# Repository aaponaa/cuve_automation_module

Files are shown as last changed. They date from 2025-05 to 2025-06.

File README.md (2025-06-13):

# 💧 Water Tank Monitor with ESP32 : RootCtrl

An all-in-one ESP32-based water tank monitoring system that measures:

- Water level using an ultrasonic sensor (AJ-SR04M / HC-SR04)
- Water temperature using DS18B20
- Outside temperature and humidity using a DHT22
- Pump/relay control via web interface or MQTT
- MQTT integration with configurable topic publishing
- Web UI with AJAX updates and settings
- WiFiManager for first-time WiFi configuration

---

## 📦 Features

- 🌀 Real-time water level calculation in cm and %
- 🌡️ Dual temperature sensing: water & ambient
- 📊 Volume estimation based on tank shape (rectangular or cylindrical)
- ⚙️ Web interface for configuration, calibration, and manual control
- 🛰️ MQTT support with configurable topics (sensor data + relay state)
- 📱 Works with Home Assistant or any MQTT broker
- 🔧 EEPROM storage of all settings (WiFi, MQTT, tank, interval, etc.)
- 🔌 Relay control from web or MQTT (`/relay_cmd`)

---

## 🧰 Hardware Required

| Component | Example GPIO | Notes |
|---|---|---|
| ESP32 WROOM-32 | - | Main microcontroller |
| Ultrasonic Sensor (AJ-SR04M / HC-SR04) | TRIG: GPIO17 / ECHO: GPIO18 | With voltage divider on ECHO |
| DS18B20 Temperature Sensor| GPIO21 | Requires 4.7kΩ pull-up to 3.3V |
| DHT22 Temp/Humidity Sensor| GPIO19 | Requires 4.7kΩ pull-up to 3.3V |
| Relay Module (SRD-05VDC-SL-C) | GPIO23 | 5V-controlled |
| Resistors | - | 2×1kΩ + 1×4.7kΩ (voltage divider) |

> ✅ Use a voltage divider (2×1kΩ + 4.7kΩ) on the ultrasonic sensor's ECHO pin to protect ESP32 GPIO from 5V logic levels.

---

## 🔌 Wiring Diagram

See Wiring Diagram :

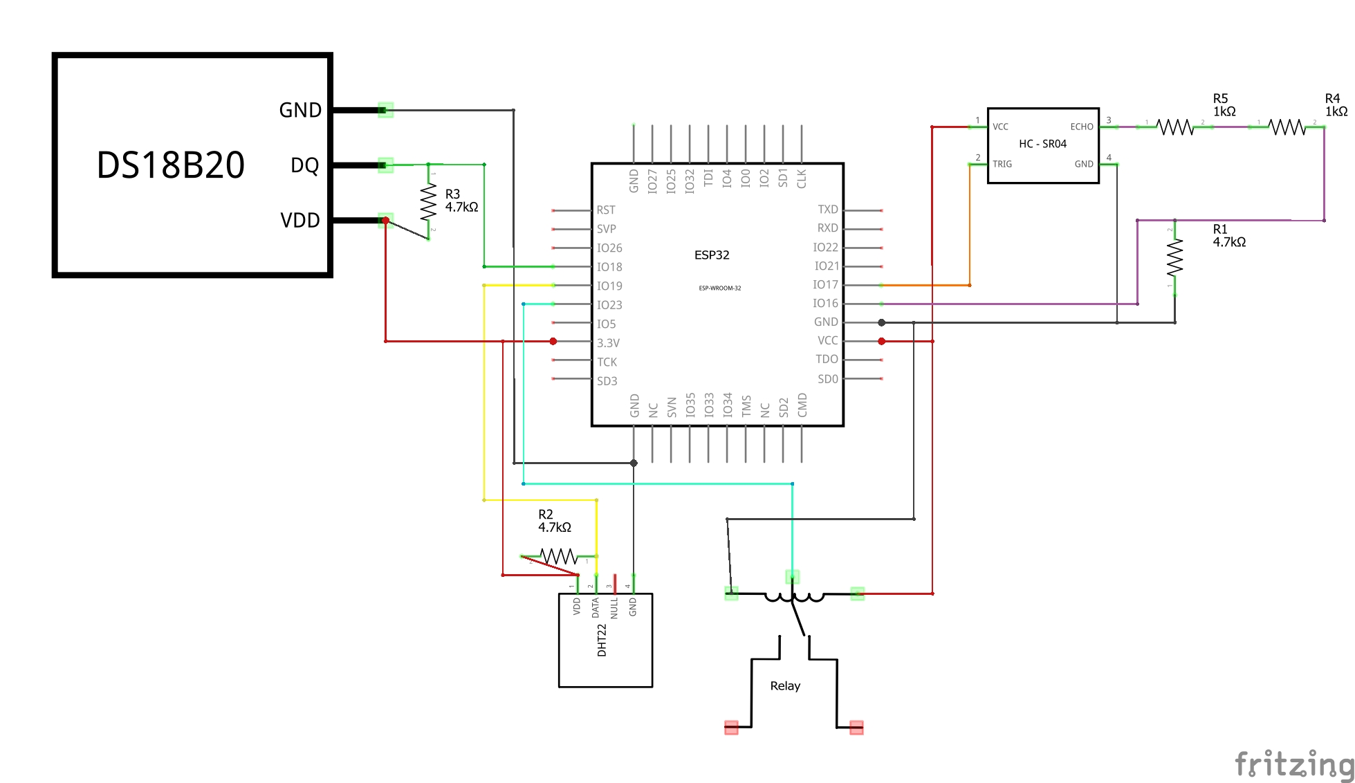
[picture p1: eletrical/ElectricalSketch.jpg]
Wiring Diagram
 

or Fritzing file for full details.

You can also reference this simplified table:

| Module | VCC  | GND | ESP32 GPIO | Resistors Needed |
| --- | ---- | --- | --- | --- |
| AJ-SR04M | 5V | GND | TRIG → GPIO17 | None |
| AJ-SR04M | | | ECHO → GPIO18 | 2×1kΩ + 1×4.7kΩ (divider) |
| DS18B20 | 3.3V | GND | DATA → GPIO21 | 1×4.7kΩ (pull-up to 3.3V) |
| DHT22 | 3.3V | GND | DATA → GPIO19 | 1×4.7kΩ (pull-up to 3.3V) |
| Relay Module | 5V | GND | IN → GPIO23 | None |

---

## 🌐 Web Interface

Accessible via browser at the ESP32 IP address.  
Features:

- Live dashboard with temperature, level, volume, % fill
- Manual relay control
- Tank configuration (shape, size)
- MQTT settings
- Update read/publish intervals
- Factory reset button

---

## ☁️ MQTT Topics

All topics are prefixed with your configured tank name (e.g. `cuve_1`).

| Topic | Description |
|---|---|
| `<prefix>/water_distance` | Distance from sensor to surface |
| `<prefix>/water_height` | Height of water in cm |
| `<prefix>/water_percent`  | Percentage fill |
| `<prefix>/water_volume` | Estimated volume in liters |
| `<prefix>/water_temp` | Water temperature (DS18B20) |
| `<prefix>/outside_temp` | Air temperature (DHT22) |
| `<prefix>/outside_humi` | Humidity (DHT22) |
| `<prefix>/relay_state` | ON/OFF state of the relay |

> To control the relay remotely:  
> Publish `"on"` or `"off"` to `<prefix>/relay_cmd`

---

## ⚙️ Settings

Stored in EEPROM via the `Preferences` API:

- Tank name
- Tank shape and dimensions
- Max water height (calibration)
- MQTT credentials and interval
- Read interval for sensors
- Enabled MQTT topics

---

## 🔧 Getting Started

1. Flash the firmware via Arduino IDE or PlatformIO
2. Connect to the WiFi AP `Tank_Automation_Config`
3. Go to `http://192.168.4.1` and enter your WiFi credentials
4. The ESP32 will reboot and be accessible on your LAN
5. Access the dashboard and configure your tank and MQTT

---

## 🚀 To Do / Ideas

- Support multiple tanks via web tabs
- OTA firmware updates
- Home Assistant full integration

---

## 🧑‍💻 Author

Benjamin Maas — [@GitHub](https://github.com/yourusername)  
Feel free to fork, use, and improve!

---

## Licence

Ce projet est sous licence **CC BY-NC 4.0** — utilisation commerciale interdite.  
Détails : [LICENSE](./LICENSE)



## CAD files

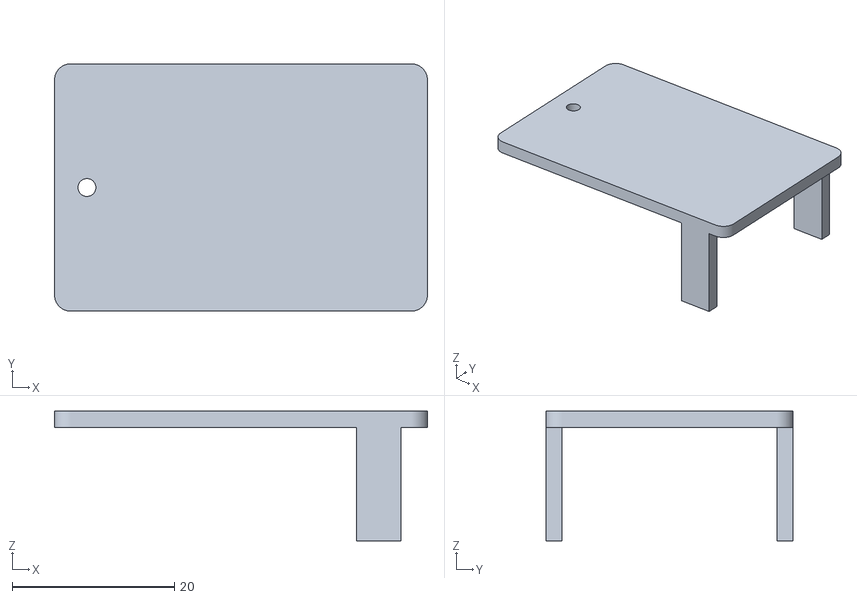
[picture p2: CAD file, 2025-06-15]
stl/relay_case-Cap.stl
46.0 x 30.5 x 16.0

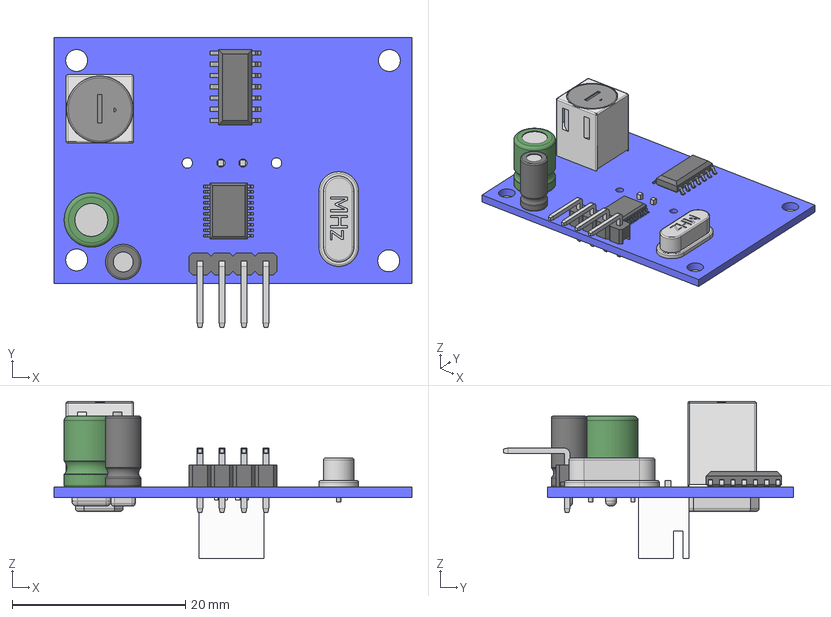
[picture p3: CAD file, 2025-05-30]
stl/StepModels/JSN20.stp
41.4 x 33.5 x 18.1 mm

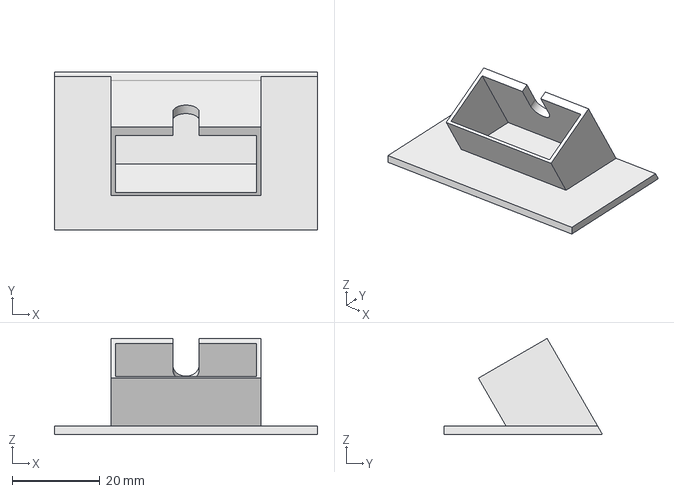
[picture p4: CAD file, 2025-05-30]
stl/Thingiverse/DHT22/DHT_Lid.FCStd
60.0 x 36.0 x 21.9 mm

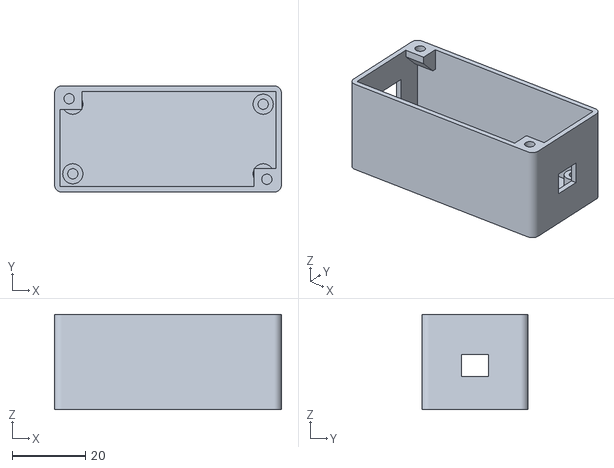
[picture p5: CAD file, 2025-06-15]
stl/alimentation_case-Box.stl
62.0 x 29.0 x 26.0

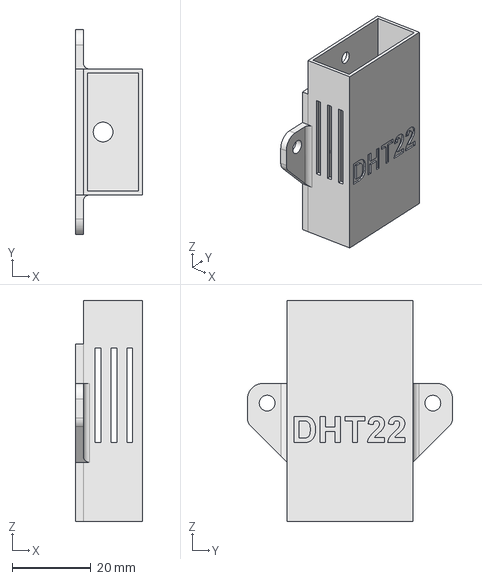
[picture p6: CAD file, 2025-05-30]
stl/Thingiverse/DHT22/DHT_Box.FCStd
17.0 x 52.0 x 56.0 mm

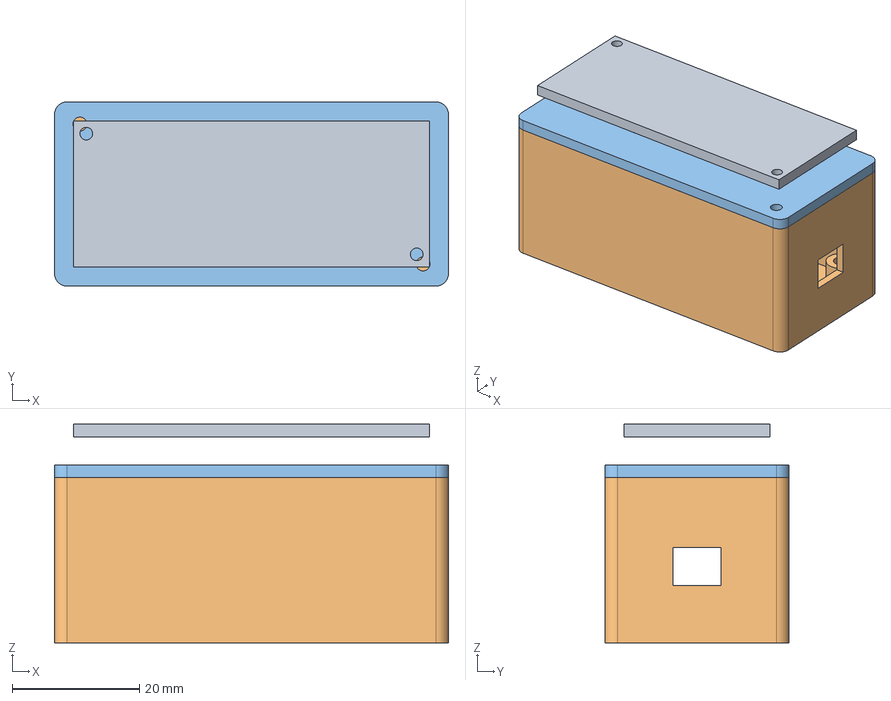
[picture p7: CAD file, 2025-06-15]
stl/alimentation_case.FCStd
62.0 x 29.0 x 34.4 mm
CardSize
Cap

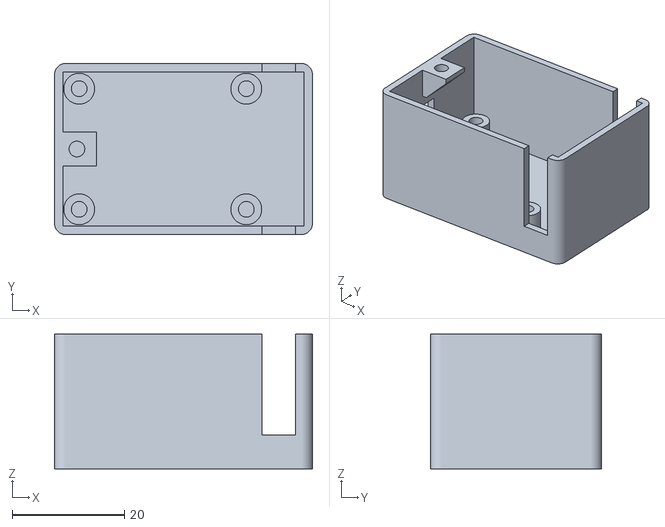
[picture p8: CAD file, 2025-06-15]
stl/relay_case-Box.stl
46.0 x 30.5 x 24.0

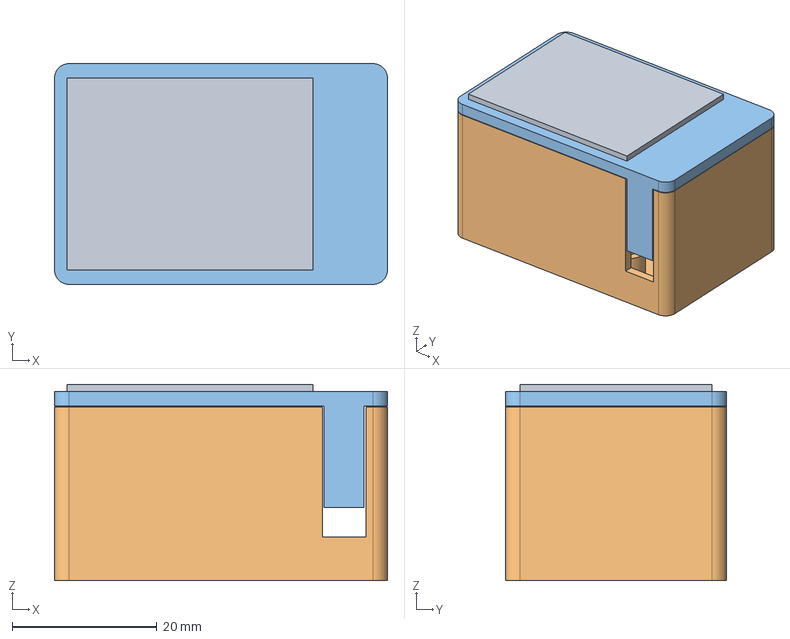
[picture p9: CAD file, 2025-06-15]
stl/relay_case.FCStd
46.0 x 30.5 x 27.1 mm
CardPatern
Cap

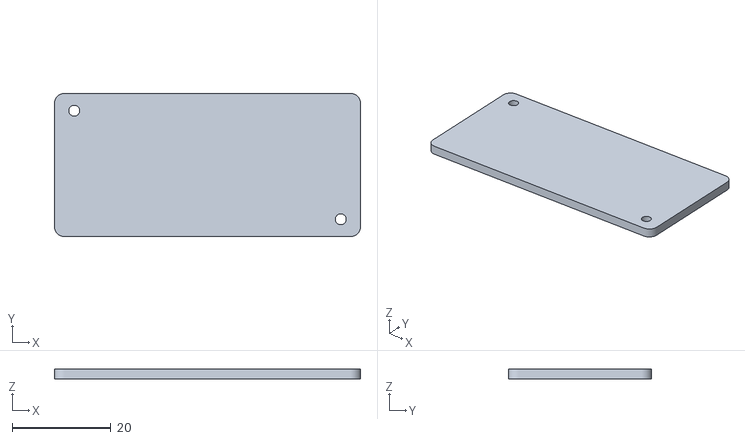
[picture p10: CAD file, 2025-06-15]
stl/alimentation_case-Cap.stl
62.0 x 29.0 x 2.00

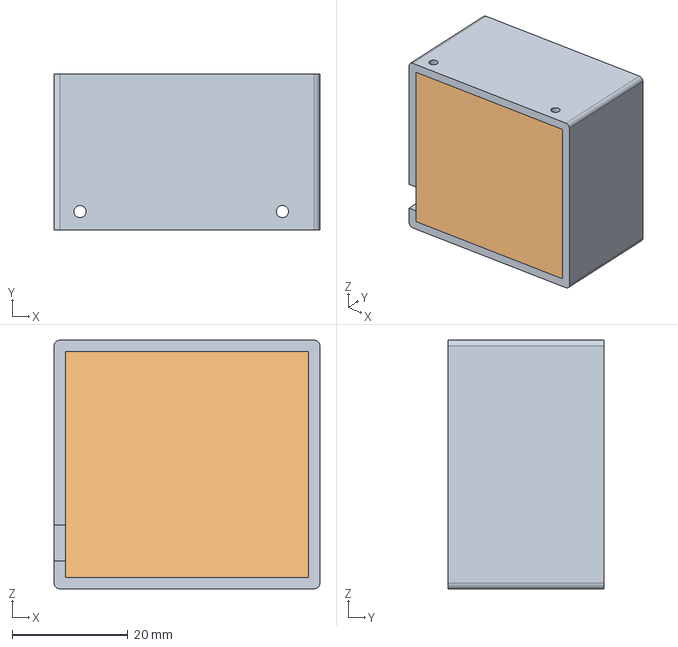
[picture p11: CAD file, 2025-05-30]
stl/sketch_case.FCStd
46.0 x 27.0 x 43.0 mm
Case
Top

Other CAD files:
stl/Thingiverse/DHT22/DHT_Box.stl
stl/Thingiverse/DHT22/DHT_Lid.stl

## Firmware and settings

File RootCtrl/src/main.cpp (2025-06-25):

#include <Arduino.h>
#include "config.h"
#include "sensors/sensors.h"
#include "sensors/relay.h"
#include "services/mqtt.h"
#include "services/web_routes.h"
#include "services/settings.h"
#include "services/wifi_handler.h"
#include "services/logger.h"

void setup() {
  Serial.begin(115200);
  
  // Initialize logger first
  Logger::getInstance().setSerialEnabled(true);
  Logger::getInstance().setMinLevel(LOG_DEBUG);
  
  LOG_INFO("SYSTEM", "Starting Water Tank Monitor " + String(FW_VERSION));
  LOG_INFO("SYSTEM", "ESP32 Chip ID: " + String((uint32_t)ESP.getEfuseMac(), HEX));
  LOG_INFO("SYSTEM", "Free heap: " + String(ESP.getFreeHeap()) + " bytes");
  
  initWifi();
  initSettings();
  initRelay();
  initSensors();
  initWebServer();
  initMqtt();
  
  LOG_INFO("SYSTEM", "Setup complete. System ready.");
}

void loop() {
  server.handleClient();
  readSensorsLoop();
  handleMqttLoop();
  
  // Log system health every 30 seconds
  static unsigned long lastHealthLog = 0;
  if (millis() - lastHealthLog > 300000) {
    LOG_DEBUG("SYSTEM", "Free heap: " + String(ESP.getFreeHeap()) + " bytes");
    LOG_DEBUG("SYSTEM", "Uptime: " + String(millis() / 1000) + " seconds");
    lastHealthLog = millis();
  }
}

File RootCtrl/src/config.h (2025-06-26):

#ifndef CONFIG_H
#define CONFIG_H

#include <Arduino.h>
#include <Preferences.h>
#include <PubSubClient.h>
#include <WebServer.h>
#include <OneWire.h>
#include <DallasTemperature.h>
#include <DHT.h>
#include <WiFiClient.h>

// ========== GENERAL SETTINGS ==========

#define FW_VERSION "v1.0.2"
extern String fw_version;

//#define USE_A02YYUW false  // Set to false to use SR04M

// ========== PIN DEFINITIONS ==========

// Ultrasonic sensors
#define TRIG_PIN 17
#define ECHO_PIN 16  // Only used for SR04M

// A02YYUW
#define SENSOR_RX_PIN 26  // A02YYUW TX → ESP32 RX (SoftwareSerial not needed with HardwareSerial2)

// DS18B20
#define ONE_WIRE_BUS 18

// DHT22
#define DHTPIN 33
#define DHTTYPE DHT22

// Relay
#define RELAY_PIN 27
#define RELAY_ACTIVE_LOW false

// ========== GLOBALS ==========

// Sensors 
extern bool use_dht;
extern bool use_ds18b20;
extern int ultrasonic_mode;  // 0 = aucune, 1 = SR04M, 2 = A02YYUW

// Web server and MQTT
extern WebServer server;
extern WiFiClient espClient;
extern PubSubClient mqtt;
extern Preferences prefs;

// Tank config
extern String tank_name;
extern int tank_shape;
extern float tank_height_cm;
extern float tank_length_cm;
extern float tank_width_cm;
extern float tank_diameter_cm;
extern float eau_max_cm;
extern float cuve_volume_l;

// Sensor values
extern float current_temp;
extern float outside_temp;
extern float outside_humi;
extern bool pump_is_on;

// Refresh intervals
extern unsigned long temp_refresh_ms;
extern unsigned long mqtt_publish_ms;

// MQTT config
extern String mqtt_host;
extern String mqtt_username;
extern String mqtt_password;
extern bool mqtt_enabled;

#endif // CONFIG_H

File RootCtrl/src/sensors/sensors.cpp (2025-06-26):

#include "sensors.h"
#include "../services/logger.h"

// DS18B20
OneWire oneWire(ONE_WIRE_BUS);
DallasTemperature ds18b20(&oneWire);

// DHT22
DHT dht(DHTPIN, DHTTYPE);

// A02YYUW via Serial2
HardwareSerial mySerial(2);  // UART2 (GPIO26 RX)

unsigned long lastDhtRead = 0;
unsigned long lastDs18Read = 0;
float last_distance = 0;

int dhtFailCount = 0;
const int maxDhtFail = 4;

void initSensors() {
  LOG_INFO("SENSORS", "Initializing sensors...");

  dht.begin();
  LOG_INFO("SENSORS", "DHT22 initialized on pin " + String(DHTPIN));
  
  ds18b20.begin();
  LOG_INFO("SENSORS", "DS18B20 initialized on pin " + String(ONE_WIRE_BUS));

  if (ultrasonic_mode == 2) {
    mySerial.begin(9600, SERIAL_8N1, SENSOR_RX_PIN, -1);  // A02YYUW
    LOG_INFO("SENSORS", "A02YYUW initialized on RX pin " + String(SENSOR_RX_PIN));
  } else if (ultrasonic_mode == 1) {
    pinMode(TRIG_PIN, OUTPUT);
    pinMode(ECHO_PIN, INPUT);
    LOG_INFO("SENSORS", "SR04M initialized - TRIG: " + String(TRIG_PIN) + ", ECHO: " + String(ECHO_PIN));
  }
}

void readSensorsLoop() {
  unsigned long now = millis();

  if (use_dht && now - lastDhtRead > temp_refresh_ms) {
    readDHT();
    lastDhtRead = now;
  }

  if (use_ds18b20 && now - lastDs18Read > temp_refresh_ms) {
    readDS18B20();
    lastDs18Read = now;
  }

  if (ultrasonic_mode == 2) {
    float newDistance = readA02YYUW();
    if (newDistance > 0) {
      last_distance = newDistance;
    }
  }
}

void readDHT() {
  float t = dht.readTemperature();
  float h = dht.readHumidity();

  if (isnan(t) || isnan(h)) {
    dhtFailCount++;
    LOG_WARNING("DHT22", "Read failed (count: " + String(dhtFailCount) + "/" + String(maxDhtFail) + ")");
  } else {
    outside_temp = t;
    outside_humi = h;
    dhtFailCount = 0;
    //LOG_DEBUG("DHT22", "Temp: " + String(t, 1) + "°C, Humidity: " + String(h, 1) + "%");
  }

  if (dhtFailCount >= maxDhtFail) {
    LOG_ERROR("DHT22", "Max failures reached, reinitializing...");
    dht.begin();
    dhtFailCount = 0;
  }
}

void readDS18B20() {
  ds18b20.requestTemperatures();
  float temp = ds18b20.getTempCByIndex(0);
  
  if (temp == DEVICE_DISCONNECTED_C) {
    LOG_ERROR("DS18B20", "Sensor disconnected or read error");
  } else {
    current_temp = temp;
    //LOG_DEBUG("DS18B20", "Water temp: " + String(temp, 1) + "°C");
  }
}

float readSR04M() {
  //LOG_DEBUG("SR04M", "Starting measurement...");
  float sum = 0;
  int validReadings = 0;
  const int samples = 5;
  
  for (int i = 0; i < samples; i++) {
    digitalWrite(TRIG_PIN, LOW);
    delayMicroseconds(2);
    digitalWrite(TRIG_PIN, HIGH);
    delayMicroseconds(10);
    digitalWrite(TRIG_PIN, LOW);
    
    long duration = pulseIn(ECHO_PIN, HIGH, 30000);
    
    if (duration > 0) {
      float distance = duration * 0.0343 / 2.0;
      sum += distance;
      validReadings++;
      //LOG_DEBUG("SR04M", "Sample " + String(i) + ": " + String(distance, 1) + " cm");
    } else {
      LOG_WARNING("SR04M", "Sample " + String(i) + " timeout");
    }
    
    delay(10);
  }
  
  if (validReadings > 0) {
    float avg = sum / validReadings;
    //LOG_INFO("SR04M", "Average distance: " + String(avg, 1) + " cm (" + String(validReadings) + " valid samples)");
    return avg;
  } else {
    LOG_ERROR("SR04M", "No valid readings");
    return -1.0;
  }
}

float readA02YYUW() {
  static unsigned long lastGoodReading = 0;
  static int consecutiveErrors = 0;

  const unsigned long timeout = 100;  // Timeout for waiting full packet (ms)
  unsigned long startMillis = millis();

  while (millis() - startMillis < timeout) {
    // Ensure we have at least 4 bytes
    if (mySerial.available() >= 4) {
      if (mySerial.peek() == 0xFF) {
        byte buffer[4];
        mySerial.readBytes(buffer, 4);

        int distance = (buffer[1] << 8) | buffer[2];
        byte checksum = (buffer[0] + buffer[1] + buffer[2]) & 0xFF;

        if (checksum == buffer[3]) {
          if (distance >= 30 && distance <= 7500) {
            float distanceCm = distance / 10.0;
            lastGoodReading = millis();
            consecutiveErrors = 0;
            LOG_INFO("A02YYUW", "Valid reading: " + String(distanceCm, 1) + " cm");
            return distanceCm;
          } else {
            LOG_WARNING("A02YYUW", "Distance out of range: " + String(distance));
          }
        } else {
          LOG_WARNING("A02YYUW", "Checksum error");
        }
      } else {
        // Discard bytes until we find 0xFF
        mySerial.read();
      }
    }
  }

  if (millis() - lastGoodReading > 5000) {
    consecutiveErrors++;
    if (consecutiveErrors % 10 == 0) {
      LOG_ERROR("A02YYUW", "No valid readings for " + String((millis() - lastGoodReading) / 1000) + " seconds");
    }
  }

  return -1.0;
}



float calculateVolumeLiters(float height_cm) {
  if (tank_shape == 1) {  // Cylinder
    return (PI * pow(tank_diameter_cm / 2, 2) * height_cm) / 1000.0;
  } else {
    return (tank_length_cm * tank_width_cm * height_cm) / 1000.0;
  }
}

float measureDistance() {
  if (ultrasonic_mode == 2) {
    return last_distance;
  } else if (ultrasonic_mode == 1) {
    return readSR04M();
  } else {
    return -1.0;
  }
}

void handleCalibrate() {
  LOG_INFO("CALIB", "Starting calibration...");
  float distance = measureDistance();
  
  if (distance > 0) {
    eau_max_cm = tank_height_cm - distance;
    prefs.begin("cuve", false);
    prefs.putFloat("eau_max", eau_max_cm);
    prefs.end();
    
    LOG_INFO("CALIB", "Calibration successful. Max water level: " + String(eau_max_cm, 1) + " cm");
  } else {
    LOG_ERROR("CALIB", "Calibration failed - invalid distance reading");
  }
  
  server.sendHeader("Location", "/");
  server.send(303);
}

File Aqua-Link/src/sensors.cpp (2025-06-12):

#include "sensors.h"

// DS18B20
OneWire oneWire(ONE_WIRE_BUS);
DallasTemperature ds18b20(&oneWire);

// DHT22
DHT dht(DHTPIN, DHTTYPE);

// A02YYUW via Serial2
HardwareSerial mySerial(2);  // UART2 (GPIO26 RX)

unsigned long lastDhtRead = 0;
unsigned long lastDs18Read = 0;
float last_distance = 0;

int dhtFailCount = 0;
const int maxDhtFail = 4;

void initSensors() {

  dht.begin();
  ds18b20.begin();

  if (USE_A02YYUW) {
    mySerial.begin(9600, SERIAL_8N1, SENSOR_RX_PIN, -1);  // RX only
  }else{
    pinMode(TRIG_PIN, OUTPUT);
    pinMode(ECHO_PIN, INPUT);
  }
}

void readSensorsLoop() {
  unsigned long now = millis();

  if (now - lastDhtRead > temp_refresh_ms) {
    readDHT();
    lastDhtRead = now;
  }

  if (now - lastDs18Read > temp_refresh_ms) {
    readDS18B20();
    lastDs18Read = now;
  }

  if (USE_A02YYUW) {
   last_distance = readA02YYUW();
  }
}

void readDHT() {
  float t = dht.readTemperature();
  float h = dht.readHumidity();

  if (isnan(t) || isnan(h)) {
    Serial.println("⚠️  DHT22 reading failed.");
    dhtFailCount++;
  } else {
    outside_temp = t;
    outside_humi = h;
    dhtFailCount = 0;
  }

  if (dhtFailCount >= maxDhtFail) {
    Serial.println("🔄 Restarting DHT22...");
    dht.begin();
    dhtFailCount = 0;
  }
}

void readDS18B20() {
  ds18b20.requestTemperatures();
  current_temp = ds18b20.getTempCByIndex(0);
}



float readSR04M() {
  float sum = 0;
  const int samples = 5;
  for (int i = 0; i < samples; i++) {
    digitalWrite(TRIG_PIN, LOW);
    delayMicroseconds(2);
    digitalWrite(TRIG_PIN, HIGH);
    delayMicroseconds(10);
    digitalWrite(TRIG_PIN, LOW);
    long duration = pulseIn(ECHO_PIN, HIGH, 30000);
    float distance = duration * 0.0343 / 2.0;
    sum += distance;
    delay(10);
  }
  return sum / samples;
}

float readA02YYUW() {
  while (mySerial.available() >= 4) {
    if (mySerial.peek() == 0xFF) {
      byte buffer[4];
      mySerial.readBytes(buffer, 4);

      if (buffer[0] == 0xFF) {
        int distance = (buffer[1] << 8) | buffer[2];
        if (distance >= 30 && distance <= 7500) {
          return distance / 10.0;  // mm to cm
        }
      }
    } else {
      mySerial.read();
    }
  }
  return -1.0;
}

float measureDistance() {
  if (USE_A02YYUW) {
    return last_distance;
  } else {
    return readSR04M();
  }
}

void handleCalibrate() {
  eau_max_cm = tank_height_cm - measureDistance();
  prefs.begin("cuve", false);
  prefs.putFloat("eau_max", eau_max_cm);
  prefs.end();
  server.sendHeader("Location", "/");
  server.send(303);
}

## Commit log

2025-05-23 adding zater temperature sensor
2025-05-23 shape of the tank and optimisatyion distance sensor median to stabilize
2025-05-24 adding pump relay integration
2025-05-24 Adding some documentation
    [ElectricalSketch.fzz]
2025-05-30 Ressources 3D Models and Electical shemas
    [DHT_Box.FCStd, DHT_Box.stl, DHT_Lid.FCStd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]
2025-05-31 Bug correction water measures and switch on and off inverted
2025-05-31 Mqtt client name unique for eache device
2025-05-31 Pump relay and Mqtt callback finaly fully working
2025-05-31 Ota Updates and DTH22 task thread isolation optimisation
2025-06-05 making new ultrasonic sensor working
2025-06-11 Relay and Alimentation Cases FreeCad files
    [alimentation_case.FCStd, relay_case.FCStd]
2025-06-12 Switching to PlatformIO Project and spliting in cleaner and smaller components
2025-06-13 removing OTA since we have update solution its was not working and no more used
    [main.cpp]
2025-06-13 updating systhem tweaked so it works no more update auto button
2025-06-15 Mqtt no more topic selection but device auto discovery in home assistant
2025-06-15 STL and FD plans for the boxes alim and relay
    [alimentation_case-Box.stl, alimentation_case-Cap.stl, alimentation_case.FCStd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]
2025-06-15 Some bug corrections with init that was not call at startup
    [config.h, main.cpp]
2025-06-15 Minor bug and corrections
    [config.h, sensors.cpp]
2025-06-17 mqtt expire_after condition in discovery so HA knows when esp is crashed or offline
    [mqtt.cpp]
2025-06-25 a way to activate and desactivate sensor in settings
2025-06-25 new sensors on shema
    [ElectricalSketch.fzz]
2025-06-26 too many log leads to bug in interface trying with less log of debug and retention
    [sensors.cpp]
2025-06-26 readA02YYUW better handle of the buffer hope this fix reading errors
    [sensors.cpp]
